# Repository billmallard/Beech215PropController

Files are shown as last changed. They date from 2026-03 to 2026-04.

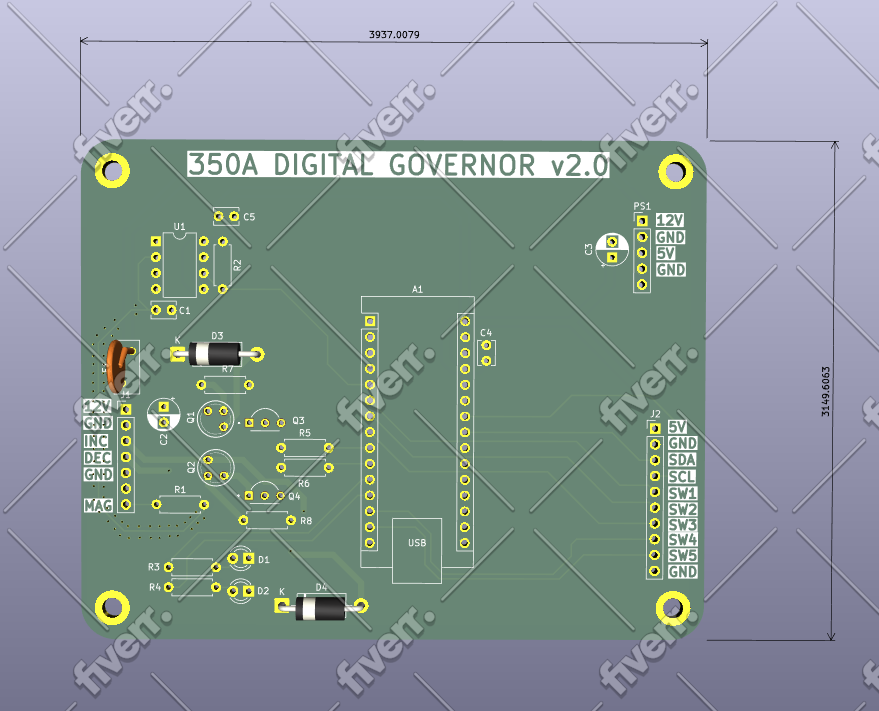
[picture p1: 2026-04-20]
hardware_april2026/Screenshot 2026-04-20 194752.png

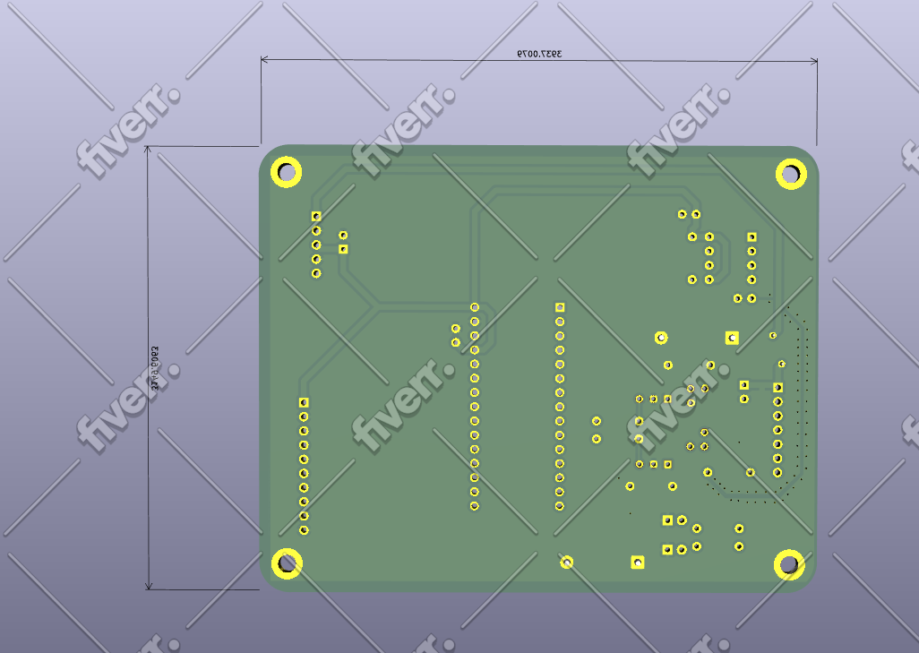
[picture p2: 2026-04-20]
hardware_april2026/Screenshot 2026-04-20 194800.png

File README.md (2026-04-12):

# Beechcraft Bonanza Electric Prop — Digital Governor Controller
### Open-Source Replacement for the Airborne Electronics 350A




> **A modern, proportional-control replacement for the Airborne Electronics 350A solid-state propeller governor — for Beechcraft Bonanza models with the Beech 215-210 electric prop.**

---

## The Problem This Solves

The original Airborne Electronics 350A (covered under STC SA2700WE) uses a **bang-bang control architecture** — the prop motor runs at full voltage until the RPM crosses the target, then reverses. This causes constant RPM hunting, which is made worse by:

- Freshly overhauled prop motors with more torque than the 50-year-old electronics expected
- Aging capacitors and resistors in the original controller that shrink the deadband
- The original panel rheostat giving no indication of what RPM is actually set
- Rough magneto signal from high-time mags degrading the RPM sensing

**This project replaces only the electronics inside the governor box.** The 7-pin Cannon connector, airframe wiring, prop motor, limit switches, and relays are all unchanged. From the aircraft's perspective, the interface is identical to the original.

## What It Does Differently

| Feature | Original 350A | This Controller |
|---|---|---|
| Control type | Bang-bang (full voltage on/off) | Proportional — slows motor near setpoint |
| Deadband | Fixed by aging analog components | Software-configurable (default ±25 RPM) |
| RPM display | None — knob position only | OLED shows set RPM and actual RPM |
| Presets | None | 5 named presets (Max, Cruise Climb, Cruise, Economy, Emergency) |
| Setpoint transition | Instant jump (causes full-duty relay surge) | Soft ramp 100 RPM/sec — smooth, no lurch |
| Fail-safe | RPM signal loss → no action | Loss of mag signal → relays de-energize, alarm displayed |
| Watchdog | None | Hardware watchdog resets MCU in 250ms if firmware stalls |
| Motor runaway protection | Limit switches only | 8-second relay timeout regardless of limit switch state |

## Who This Is For

Any Beechcraft Bonanza (straight 35 through G35, A35–G35) equipped with:
- The Beech 215-210 electric prop
- An existing Airborne Electronics 350A installation (STC SA2700WE)

If you have the stock mechanical governor, this is not applicable.

---

## Regulatory Note

This project is designed for **owner-produced parts** under 14 CFR Part 21.303. The STC SA2700WE defines the system by its external interface — the 7-pin connector, wire assignments, and functional behavior — all of which are preserved exactly. The electronics inside the governor housing are replaced. **This is a major alteration and requires FAA Form 337 approval signed by an IA.** See [docs/REGULATORY.md](docs/REGULATORY.md) for a detailed discussion and suggested 337 language.

---

## Hardware Overview

The system consists of two units:

**Governor Box** (replaces the 350A housing, mounts in the same location):
- Arduino Nano (ATmega328P)
- 6N137 optocoupler (galvanic isolation of magneto P-lead)
- ULN2003A Darlington array (relay driver)
- LM2596S-5V DC-DC switching regulator
- Supporting passives

**Panel Unit** (replaces the knob/rheostat assembly):
- SSD1306 1.3" OLED display (128×64, I2C)
- 5-position rotary switch (one detent per preset — Lorlin CK1024 or Grayhill 56-series)
- Original prop control knob reuses directly on the switch shaft

The PCB is a 100mm × 80mm 2-layer FR4 board, designed for JLCPCB fabrication at approximately **$2 for 5 boards**. The panel cable is 10 conductors (simplified from earlier designs).

---

## Repository Structure

```
bonanza-prop-governor/
├── README.md                    ← You are here
├── docs/
│   ├── ASSEMBLY.md              ← Step-by-step build instructions
│   ├── BENCH_TEST.md            ← Ground test procedure before aircraft installation
│   ├── WIRING.md                ← Connector pinout and wiring reference
│   ├── REGULATORY.md            ← FAA owner-produced parts guidance, 337 language
│   └── TROUBLESHOOTING.md       ← Fault codes, common issues
├── firmware/
│   └── governor_350A/
│       ├── README.md            ← Flashing guide, serial console, unit tests
│       ├── governor_350A.ino    ← Arduino sketch (fully commented)
│       ├── platformio.ini       ← PlatformIO build config (AVR + native test)
│       └── test/                ← Unity unit tests (runs on desktop, no hardware)
└── hardware/
    ├── 350A_governor.kicad_pcb  ← KiCad PCB file (open in KiCad 7+)
    ├── 350A_governor_JLCPCB.zip ← Ready-to-upload Gerber package for JLCPCB
    └── BOM.md                   ← Bill of materials with part numbers and sources
```

---

## Quick Start

1. **Order the PCB** — Upload `hardware/350A_governor_JLCPCB.zip` to [jlcpcb.com](https://jlcpcb.com). Default settings (2-layer, FR4, 1.6mm, HASL, green) are fine.
2. **Order components** — See [hardware/BOM.md](hardware/BOM.md). Total ~$55–95 for a complete build.
3. **Assemble** — Follow [docs/ASSEMBLY.md](docs/ASSEMBLY.md). All through-hole components; no SMD soldering.
4. **Flash firmware** — See [firmware/governor_350A/README.md](firmware/governor_350A/README.md) for full instructions (Arduino IDE, PlatformIO, and CLI). Set `PULSES_PER_REV` for your engine before flashing.
5. **Bench test** — Build the test harness described in [docs/BENCH_TEST.md](docs/BENCH_TEST.md) and verify operation before touching the aircraft.
6. **Install** — Follow [docs/ASSEMBLY.md](docs/ASSEMBLY.md) aircraft installation section. Have your IA present.

---

## Engine Compatibility

Set `PULSES_PER_REV` in the firmware before flashing:

| Engine | Cylinders | PULSES_PER_REV |
|---|---|---|
| Continental IO-470 | 6 | 3 |
| Continental IO-520 | 6 | 3 |
| Continental E-185/E-225 | 6 | 3 |
| Lycoming O-435 | 6 | 3 |

All early Bonanzas use Continental 6-cylinder engines. `PULSES_PER_REV = 3` is correct for all of them.

---

## Contributing

This project is maintained by the Bonanza owner community. Pull requests welcome for:
- Firmware improvements (better control algorithms, additional safety checks)
- Documentation corrections
- Hardware revisions (alternative component footprints, panel unit PCB)
- Flight test data and tuning recommendations

Please open an issue before starting significant work so efforts aren't duplicated.

---

## Security

This repository uses layered secret-prevention controls. See [SECURITY.md](SECURITY.md) for the full policy including vulnerability reporting and incident response steps.

| Layer | Tool | Trigger |
|---|---|---|
| Local pre-commit | `tools/security/scan_secrets.py` | Every `git commit` (staged files) |
| CI — SAST | CodeQL (C/C++ + Python) | Push, PR, weekly |
| CI — Secret scan | Gitleaks | Push, PR, weekly (full history) |

**Quick setup after cloning:**
```
pip install pre-commit
pre-commit install
```

Recommended GitHub repository settings: enable **Secret scanning**, **Push protection**, and **Dependabot** (Settings → Security).

---

## License

MIT License. See LICENSE file. This hardware and firmware may be freely built, modified, and used for personal aircraft. Commercial reproduction or sale requires separate arrangement.

---

## Acknowledgments

Richard Keiter of Airborne Electronics, Healdsburg CA, designed the original 350A and made it repairable by owners. This project is built on his philosophy. The complete original documentation is preserved in [docs/original_350A/](docs/original_350A/) for reference.

---

*This project is not affiliated with Beechcraft, Textron Aviation, or Airborne Electronics. It is an independent owner-community project. Install only with appropriate FAA authorization.*

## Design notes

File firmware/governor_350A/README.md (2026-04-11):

# Firmware — governor_350A

Arduino sketch for the Beechcraft Bonanza digital prop governor. Targets the **Arduino Nano (ATmega328P, 5V, 16MHz)**.

---

## Before You Flash

**One setting must be correct for your engine before uploading:**

```cpp
// governor_350A.ino — top of file
#define PULSES_PER_REV  3   // 6-cyl Continental (IO-470, IO-520, E-185/E-225)
                            // Change to 2 for 4-cylinder engines
```

All early Bonanzas use Continental 6-cylinder engines. `3` is correct for all of them. Getting this wrong causes the RPM reading to be off by 33% and the governor will not hold correctly.

---

## Flashing the Firmware

### Option A — Arduino IDE (simplest)

1. **Install Arduino IDE 2.x** from [arduino.cc/en/software](https://www.arduino.cc/en/software)

2. **Install required libraries** via *Tools → Manage Libraries*:
   - `Adafruit SSD1306` (by Adafruit) — installs `Adafruit GFX Library` automatically
   - Accept all dependency installs when prompted

3. **Open the sketch** — `File → Open → firmware/governor_350A/governor_350A.ino`

4. **Set the board** — *Tools → Board → Arduino AVR Boards → Arduino Nano*

5. **Set the processor** — *Tools → Processor → ATmega328P*
   > If upload fails with the default setting, try *ATmega328P (Old Bootloader)*. Nanos purchased after ~2018 typically have the old bootloader despite being sold as standard.

6. **Select the port** — *Tools → Port → COM? (Arduino Nano)*
   - On Windows: check Device Manager under Ports (COM & LPT)
   - On Mac/Linux: `/dev/cu.usbserial-*` or `/dev/ttyUSB*`

7. **Verify** (optional) — Click the tick icon (✓) to compile without uploading. Confirms no errors before touching the board.

8. **Upload** — Click the arrow icon (→). The IDE compiles and flashes. The Nano's RX/TX LEDs will blink rapidly during upload, then the board resets and runs.

9. **Open Serial Monitor** — *Tools → Serial Monitor*, baud rate `9600`. You should see:
   ```
   350A Digital Governor v2.0
   PULSES_PER_REV=3
   RAMP_RATE=100 RPM/sec
   Boot: SW position 3 (CRUISE)
   Ready. Type ? for commands.
   ```

---

### Option B — PlatformIO (recommended for ongoing development)

PlatformIO integrates with VS Code and handles library management automatically. A `platformio.ini` is included in this directory.

1. **Install VS Code** from [code.visualstudio.com](https://code.visualstudio.com)

2. **Install the PlatformIO IDE extension** — search *PlatformIO IDE* in the VS Code Extensions panel

3. **Open the firmware directory** — *File → Open Folder → firmware/governor_350A*
   > Open the `governor_350A` folder itself, not the repo root. PlatformIO expects `platformio.ini` to be at the folder root.

4. **Set `PULSES_PER_REV`** in `governor_350A.ino` if needed.

5. **Build** — Click the checkmark (✓) in the PlatformIO toolbar (bottom status bar), or run:
   ```
   pio run
   ```
   PlatformIO auto-downloads the AVR toolchain and Adafruit libraries on first build.

6. **Upload** — Connect the Nano via USB, then click the arrow icon (→) in the toolbar, or:
   ```
   pio run --target upload
   ```

7. **Serial monitor** — Click the plug icon in the toolbar, or:
   ```
   pio device monitor --baud 9600
   ```

**Expected build output (approximate):**
```
RAM:   [=======   ]  66.7% (used 1367 bytes from 2048 bytes)
Flash: [========  ]  78.1% (used 23998 bytes from 30720 bytes)
[SUCCESS]
```

Flash usage is high because the Adafruit SSD1306 + GFX libraries are large. There is approximately 6KB of flash headroom available. RAM has ~680 bytes free at runtime; the call stack lives here so don't add large local arrays.

---

### Option C — Arduino CLI (headless / automation)

Useful for CI or machines without a GUI.

1. **Install arduino-cli** — download from [arduino.cc/en/software](https://www.arduino.cc/en/software) (scroll to CLI section), or:
   ```bash
   # macOS
   brew install arduino-cli

   # Linux / Windows (PowerShell)
   curl -fsSL https://raw.githubusercontent.com/arduino/arduino-cli/master/install.sh | sh
   ```

2. **Initialize and install the AVR core:**
   ```bash
   arduino-cli config init
   arduino-cli core update-index
   arduino-cli core install arduino:avr
   ```

3. **Install required libraries:**
   ```bash
   arduino-cli lib install "Adafruit SSD1306"
   arduino-cli lib install "Adafruit GFX Library"
   ```

4. **Compile:**
   ```bash
   arduino-cli compile \
     --fqbn arduino:avr:nano:cpu=atmega328 \
     firmware/governor_350A/governor_350A.ino
   ```
   > For the old bootloader variant: `--fqbn arduino:avr:nano:cpu=atmega328old`

5. **Find the port:**
   ```bash
   arduino-cli board list
   ```

6. **Upload:**
   ```bash
   arduino-cli upload \
     --fqbn arduino:avr:nano:cpu=atmega328 \
     --port /dev/ttyUSB0 \
     firmware/governor_350A/governor_350A.ino
   ```
   Replace `/dev/ttyUSB0` with your actual port (`COMx` on Windows).

---

## Serial Debug Console

While the Nano is connected via USB, a debug console is available at **9600 baud**. Open any serial terminal (Arduino IDE Serial Monitor, PlatformIO monitor, `screen`, PuTTY, etc.).

| Command | Action |
|---|---|
| `?` | Print command help |
| `s` | Print full status line |
| `a` | Switch to AUTO mode |
| `m` | Switch to MANUAL mode, disable relays |
| `c` | Clear active alarm |
| `1`–`5` | Simulate rotary switch position (for bench testing without hardware) |

**Example status output (`s` command):**
```
Mode=AUTO SW=CRUISE Target=2300 Ramped=2300 ACT=2287 Err=13 Relay=OFF
```

When in AUTO mode, the status line prints automatically every 2 seconds.

---

## Unit Tests

The firmware includes a [Unity](https://github.com/ThrowTheSwitch/Unity)-based test suite that runs on the **native desktop** — no Arduino hardware required.

### What Is Tested

Tests mock all Arduino/AVR hardware APIs (GPIO, timers, EEPROM, I2C, watchdog) and compile the `.ino` directly as a C++ translation unit. This allows the pure logic functions to be executed and verified offline.

| Module | Test cases | What is verified |
|---|---|---|
| `calculateRPM()` | 6 | Zero when no pulse interval; zero when mag signal timeout; correct RPM at all four preset values (2200, 2300, 2450, 2650) with 3 PPR; rolling average dampens a spike without wild RPM reading |
| `magSignalLost()` | 3 | Returns false when signal is fresh; returns false 1 ms before the 2-second timeout; returns true 1 ms after the timeout |
| `updateRamp()` | 5 | Ramps up toward higher target at correct rate (100 RPM/sec); ramps down toward lower target; snaps to target when remaining gap is smaller than one step; never overshoots; skips entirely when fullCoarse preset is active |
| `runControlLoop()` | 10 | Commands INC relay when RPM is below setpoint; commands DEC relay when above; cuts off both relays inside the ±25 RPM deadband; does not act in MANUAL mode; triggers ALARM and de-energizes relays on mag signal loss; triggers ALARM on RPM below 400 or above 3500; drives DEC continuously in fullCoarse (EMERGENCY) mode; commands full relay duty when error ≥ PROP_ZONE_RPM; commands proportional duty when error is inside the proportional zone |

**Total: 24 tests, 0 failures.**

### What Is Not Testable Without Hardware

| Functionality | Why it can't be unit tested |
|---|---|
| `readSwitch()` debounce | Requires `digitalRead()` returning a changing sequence over real time. The static state variables inside the function also can't be reset from outside. |
| Relay contact waveform (actual duty cycle) | The proportional relay drive calculates `millis() % CONTROL_INTERVAL_MS` to place the on-pulse within the 100ms window. Verifying the GPIO waveform shape requires a real-time environment with accurate timer semantics. |
| OLED rendering | `updateDisplay()` has no observable output in a mock environment. OLED correctness is verified visually during bench test. |
| Watchdog reset behavior | The ATmega328P watchdog timer is a hardware peripheral. `wdt_enable()` / `wdt_reset()` are no-ops in the test mock. Watchdog function is inherent to the MCU and doesn't require software verification. |
| EEPROM persistence across power cycles | The mock EEPROM is a RAM array that resets at program start. Testing true non-volatile persistence requires either the physical chip or a more complete simulator. |
| `loadSettings()` round-trip | Depends on EEPROM persistence. Functional correctness is verified during bench test by power-cycling and confirming settings are retained. |
| Optocoupler signal conditioning | Analog/electrical behavior of the 6N137 (slew rate, noise rejection). Verified with an oscilloscope at the bench test stage per [docs/BENCH_TEST.md](../../docs/BENCH_TEST.md). |
| Full system integration | End-to-end behavior (mag signal → interrupt → RPM → relay → motor → RPM) requires the complete hardware assembly. See `docs/BENCH_TEST.md` for the full ground test procedure. |

### Running the Tests

#### With PlatformIO and GCC (Linux / macOS / Windows with MinGW)

```bash
cd firmware/governor_350A
pio test -e native
```

PlatformIO automatically downloads the Unity library and compiles the test suite. Requires `gcc` / `g++` in your PATH.

- **Linux:** `sudo apt install gcc build-essential`
- **macOS:** `xcode-select --install`
- **Windows:** Install [MSYS2](https://www.msys2.org), then `pacman -S mingw-w64-x86_64-gcc`, and add `C:\msys64\mingw64\bin` to your PATH

#### With MSVC on Windows (VS 2017/2019/2022 Build Tools)

A batch script is provided for Windows machines with Visual Studio Build Tools but no MinGW:

```bat
cd firmware\governor_350A
.pio\build_test.bat
.pio\test_firmware.exe
```

> `build_test.bat` is generated in `.pio\` (gitignored). If it's missing, re-run `pio test -e native` once — it will fail at link but will have downloaded Unity and created the `.pio` directories. Then recreate the batch file or compile manually using the MSVC command in the next section.

**Manual MSVC compile** (if the batch file is missing):
```bat
call "C:\Program Files (x86)\Microsoft Visual Studio\2017\BuildTools\VC\Auxiliary\Build\vcvars64.bat"

cl.exe /EHsc /std:c++14 /nologo ^
  /I "test\mocks" ^
  /I ".pio\libdeps\native\Unity\src" ^
  "test\test_firmware\test_firmware.cpp" ^
  ".pio\libdeps\native\Unity\src\unity.c" ^
  /Fe:".pio\test_firmware.exe"

.pio\test_firmware.exe
```

Adjust the VS path for your installed version (2017/2019/2022).

#### Expected output

```
test\test_firmware\test_firmware.cpp:319:test_rpm_zero_when_no_pulse_interval:PASS
test\test_firmware\test_firmware.cpp:320:test_rpm_zero_when_mag_signal_lost:PASS
...
test\test_firmware\test_firmware.cpp:348:test_control_proportional_duty_in_prop_zone:PASS

-----------------------
24 Tests 0 Failures 0 Ignored
OK
```

### Test File Layout

```
firmware/governor_350A/
├── governor_350A.ino          ← Firmware source
├── platformio.ini             ← Build config (AVR + native test environments)
└── test/
    ├── mocks/                 ← Arduino/AVR API stubs for native compilation
    │   ├── Arduino.h          ← millis(), micros(), digitalRead/Write, Serial, String
    │   ├── Wire.h             ← TwoWire stub
    │   ├── EEPROM.h           ← RAM-backed EEPROM stub
    │   ├── Adafruit_GFX.h     ← Empty stub (not exercised by logic tests)
    │   ├── Adafruit_SSD1306.h ← No-op method stubs
    │   └── avr/
    │       └── wdt.h          ← wdt_enable/wdt_reset no-ops
    └── test_firmware/
        └── test_firmware.cpp  ← 24 Unity test cases
```

---

## Tuning Parameters

All tuning constants are `#define`d at the top of the sketch. Defaults are conservative and appropriate for a first installation. Adjust after confirming basic operation.

| Constant | Default | Effect |
|---|---|---|
| `DEADBAND_RPM` | 25 | No correction within ±25 RPM of setpoint. Increase if relay chatters at target; decrease for tighter hold. |
| `PROP_ZONE_RPM` | 75 | Proportional slowdown starts this far from setpoint. Must be > `DEADBAND_RPM`. |
| `MIN_DUTY_PCT` | 25 | Minimum relay duty in the proportional zone (prevents relay from switching too briefly to move the motor). |
| `RAMP_RATE_RPM_PER_SEC` | 100 | How fast the setpoint walks to a new preset. At 100 RPM/sec, ECO→MAX (450 RPM) takes ~4.5 seconds. |
| `MAG_TIMEOUT_MS` | 2000 | Alarm if no magneto pulse for this long (engine idle produces ~90 Hz; 2 seconds is 180 missed pulses). |
| `MAX_RELAY_MS` | 8000 | Safety: cut relay if it's been continuously on for 8 seconds without the RPM moving. |
| `CONTROL_INTERVAL_MS` | 100 | Control loop cadence. Also the PWM period for proportional duty output. |

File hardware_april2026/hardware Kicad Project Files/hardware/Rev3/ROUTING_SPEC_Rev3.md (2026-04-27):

# 350A Governor PCB — Rev 3 Routing Specification
# High-Side Relay Driver (NPN + PNP)

This document gives **explicit pad-to-net assignments** for all new Rev 2 components.
Use it to assign nets in the PCB editor before routing traces.

---

## Footprint Pin Reference

### Q3, Q4 — 2N2222A NPN (footprint: `2N2222A:TO92254P470H750-3`)

Three inline pads. Square pad (pad 1) is marked with a silkscreen dot.
Looking at the **flat face** of the transistor body:

```
[Pad 1 / E]  [Pad 2 / B]  [Pad 3 / C]
  Emitter      Base        Collector
  (square)     (round)     (round)
```

### Q1, Q2 — 2N2907A PNP (footprint: `2N2907A_:TO18`)

> **Note:** The revision brief specified TO-92. The delivered footprint is TO-18 (metal can,
> triangular pin arrangement). Electrically compatible but physically different. If you wish
> to change to TO-92 for consistency with the brief, use the standard KiCad
> `Package_TO_SOT_THT:TO-92_Inline` footprint (EBC left-to-right). The pad assignments
> below are for the TO-18 footprint as placed.

Pin layout (view from bottom, leads facing you):

```
Pad 1 (E)   Pad 2 (B)
  (-1.27,    (+1.27,
   +1.27)     +1.27)

             Pad 3 (C)
             (+1.27,
              -1.27)
```

| Pad | Function |
|-----|---|
| 1 | Emitter  |
| 2 | Base |
| 3 | Collector|

---

## Required Net Assignment — Per Pad

### Channel 1 — INC (Q3, Q1, R5, R7, D4)

| Ref | Pad | Net | Notes |
|-----|-----|-----|---|
| Q3 | 1 (E) | `GND` | NPN emitter to ground |
| Q3 | 2 (B) | `Q3_BASE` | Receives drive signal via R5 |
| Q3 | 3 (C) | `Q3_COLL` | Shared node: R7 pin 1 + Q1 pad 2 |
| R5 | 1 | `Q3_BASE` | Connects to Q3 base |
| R5 | 2 | `D6_INC` | ✅ Already routed — do not change |
| R7 | 1 | `Q3_COLL` | Shared node with Q3 collector and Q1 base |
| R7 | 2 | `12V_RAW` | Pull-up to +12V — keeps PNP off when NPN is off |
| Q1 | 1 (E) | `12V_RAW` | PNP emitter to +12V supply rail |
| Q1 | 2 (B) | `Q3_COLL` | Shared node: Q3 collector + R7 pin 1 |
| Q1 | 3 (C) | `INC_RELAY` | Drives INC relay coil via J1 |
| D4 | 1 (cathode) | `12V_RAW` | ⚠️ Currently unrouted — must connect to +12V |
| D4 | 2 (anode) | `INC_RELAY` | ✅ Already routed — do not change |

**`Q3_BASE` and `Q3_COLL` are internal nets** — name them whatever you like in KiCad,
but they must connect *only* the pads listed above.

---

### Channel 2 — DEC (Q4, Q2, R6, R8, D3)

| Ref | Pad | Net | Notes |
|-----|-----|-----|---|
| Q4 | 1 (E) | `GND` | NPN emitter to ground |
| Q4 | 2 (B) | `Q4_BASE` | Receives drive signal via R6 |
| Q4 | 3 (C) | `Q4_COLL` | Shared node: R8 pin 1 + Q2 pad 2 |
| R6 | 1 | `Q4_BASE` | Connects to Q4 base |
| R6 | 2 | `D7_DEC` | ✅ Already routed — do not change |
| R8 | 1 | `Q4_COLL` | Shared node with Q4 collector and Q2 base |
| R8 | 2 | `12V_RAW` | Pull-up to +12V |
| Q2 | 1 (E) | `12V_RAW` | PNP emitter to +12V supply rail |
| Q2 | 2 (B) | `Q4_COLL` | Shared node: Q4 collector + R8 pin 1 |
| Q2 | 3 (C) | `DEC_RELAY` | Drives DEC relay coil via J1 |
| D3 | 1 (cathode) | `12V_RAW` | ✅ Already routed — do not change |
| D3 | 2 (anode) | `DEC_RELAY` | ✅ Already routed — do not change |

---

### Fuse — F1

> **Important:** F1 must be in *series* on the +12V input, not connected pad-to-pad on
> the same net. This requires splitting the existing `12V_RAW` net at the power input.

| Ref | Pad | Net | Notes |
|-----|-----|-----|---|
| F1 | 1 | `12V_IN` | From power input connector (upstream of fuse) |
| F1 | 2 | `12V_RAW` | Protected rail (downstream — feeds Q1/Q2 emitters, R7/R8) |

**How to implement in KiCad:**
1. Identify the pad on J1 (or PS1) that is the +12V input to the board.
2. Break the existing `12V_RAW` trace between that pad and the rest of the board.
3. Rename the power-input pad's net to `12V_IN`.
4. Route: connector `12V_IN` pad → F1 pad 1 → F1 pad 2 → existing `12V_RAW` bus.

---

## Errors to Correct in Current Revision

The following incorrect connections from the current PCB must be **removed** before re-routing:

| Ref | Pad | Current (wrong) net | Correct net |
|-----|-----|---|---|
| Q3  | 2 | `GND` | `Q3_BASE` |
| Q4  | 2 | `GND` | `Q4_BASE` |
| Q1  | 1 | `DEC_RELAY` | `12V_RAW` |
| Q2  | 1 | `INC_RELAY` | `12V_RAW` |
| F1  | 1 | `12V_RAW` | `12V_IN` |
| F1  | 2 | `12V_RAW` | `12V_RAW` (unchanged but pad 1 must change) |

---

## What Was Correct (do not change)

| Ref | Pad | Net | Status |
|-----|-----|-----|---|
| R5 | 2 | `D6_INC` | ✅ |
| R6 | 2 | `D7_DEC` | ✅ |
| D3 | 1 | `12V_RAW` | ✅ |
| D3 | 2 | `DEC_RELAY` | ✅ |
| D4 | 2 | `INC_RELAY` | ✅ |

---

## Re-run DRC After Routing

The existing DRC report (`DRC.rpt`) is dated **2026-03-12** and does not reflect the
Rev 2 components. After completing all net assignments and routing:

1. **Edit → Fill All Zones** (refresh GND pour)
2. **Inspect → Design Rules Checker** — must show 0 errors, 0 unconnected pads
3. Save a new `DRC.rpt`
4. Regenerate Gerbers: **File → Fabrication Outputs → Gerbers**

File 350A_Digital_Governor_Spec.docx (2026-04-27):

Airborne Electronics 350A

Digital Propeller Governor Replacement

Technical Specification · Revision 3.0 · April 2026

An open-source digital replacement for the Airborne Electronics 350A propeller governor, designed for Beechcraft Bonanza aircraft equipped with the Hartzell electric propeller system under STC SA2700WE.

GitHub: https://github.com/billmallard/Beech215PropController

Reference Aircraft: Beechcraft A-35 Bonanza

FOR EXPERIMENTAL AND DEVELOPMENT USE ONLY — NOT FAA APPROVED

# 1. Project Overview

This project implements a digital drop-in replacement for the Airborne Electronics 350A propeller governor used on Beechcraft Bonanza aircraft equipped with the Hartzell electric propeller pitch control system. The original 350A uses analog bang-bang (on/off) control logic with a panel rheostat for RPM selection. This replacement retains full electrical compatibility with the aircraft's existing 7-pin MS3106 cannon connector wiring while replacing the control logic with a microcontroller-based PID-influenced governor featuring a 5-position rotary switch for discrete RPM preset selection.

## 1.1 Design Goals

- Drop-in electrical replacement — no aircraft wiring modifications required
- Eliminate RPM hunting present in worn or aging 350A units
- Precise RPM hold using digital pulse counting from the magneto P-lead
- Five discrete RPM presets via panel-mounted rotary switch
- OLED display showing live RPM, selected mode, and governor status
- Open-source hardware and firmware for community improvement
- Custom-machined aluminum panel inserts for a factory-quality cockpit appearance

## 1.2 Compatibility

Parameter | Value
Aircraft | Beechcraft 35-series Bonanza (A-35 and variants)
Engine | Continental IO-470 / IO-520 (6-cylinder)
Propeller System | Hartzell electric pitch change motor
STC | SA2700WE (Airborne Electronics 350A)
Connector | Amphenol MS3106A-14S-7S (7-pin circular)
Aircraft Power | 12V DC nominal (11–14V operating range)

# 2. System Architecture

The controller is built around an Arduino Nano (ATmega328P) with supporting circuitry on a custom 2-layer PCB. The design uses optocoupler isolation on the magneto pulse input, NPN+PNP discrete transistor pairs (Q1–Q4) for relay drive, and a regulated 5V supply derived from aircraft 12V bus power.

## 2.1 Signal Chain

- Magneto P-lead (Pin H) → 10kΩ isolating resistor → 6N137 optocoupler → Arduino INT0 (D2)
- Arduino D6/D7 → NPN+PNP transistor pairs (Q3/Q1, Q4/Q2) → INC/DEC relay coils (Pin C / Pin D)
- Panel rotary switch (5-position) → Arduino D3/D4/D5/D10/D11
- Arduino A4/A5 (I2C SDA/SCL) → 0.96" OLED display (SSD1306)
- Aircraft 12V (Pin A) → LM2596 buck module → 5V regulated → Arduino Nano VIN

## 2.2 RPM Sensing

RPM is derived from the right magneto P-lead pulse train. The Continental IO-470/IO-520 fires 3 pulses per revolution (one per cylinder pair per rotation). The 6N137 high-speed optocoupler provides electrical isolation from the magneto circuit and level-shifts the signal to 5V logic. The Arduino captures rising edges on INT0 using hardware interrupt, computing RPM over a 250ms measurement window for a balance of responsiveness and stability.

NOTE: The 10kΩ series resistor on Pin H is part of the original 350A wiring harness. This resistor must remain in the circuit. Do not bypass it.

## 2.3 Governor Logic

The governor uses a three-zone control strategy:

- Deadband (±25 RPM): No relay action. Prevents relay chatter at steady cruise.
- Proportional Zone (±75 RPM): Relay pulse duration scaled to error magnitude. Provides smooth, damped correction.
- Full Correction (>75 RPM error): Maximum relay duration (capped at 8 seconds) for large deviations.

On RPM preset change, the target ramps at 100 RPM/second to prevent abrupt pitch commands. Position 5 (EMER) bypasses governor logic entirely and commands immediate full-coarse pitch.

# 3. Hardware

## 3.1 PCB Specifications

Parameter | Specification
Board Size | 100mm × 80mm
Layers | 2-layer FR4
Copper Weight | 1oz
Surface Finish | HASL or ENIG
Mounting | 4× M3 through-holes at corners
PCB Tool | KiCad 10
Fab Target | JLCPCB (2-layer, standard spec)

## 3.2 Component List

Ref | Component | Value/Type | Part / Source | Notes
A1 | Arduino Nano | ATmega328P | LAFVIN Nano V3.0 / Amazon | CH340 USB; install driver
U1 | Optocoupler | 6N137 | DigiKey #1731495 | DIP-8; Vishay
PS1 | Buck Regulator | LM2596 5V | Amazon 5-pack | Adjust to 5.0V before install
J1 | Governor Connector | 7-pin MS3106A | Aircraft Spruce / DigiKey | MS3106A-14S-7S mating plug
J2 | Panel Connector | 10-pin header | 2.54mm male header | Switch + display harness
DISP | OLED Display | 1.3" SSD1306 | UCTRONICS / Amazon | I2C 0x3C; yellow+blue
R1 | Resistor | 10kΩ | DigiKey 10KEBK-ND | Magneto input isolation
R2 | Resistor | 4.7kΩ | DigiKey 4.7KEBK-ND | Optocoupler bias
R3, R4 | Resistors | 330Ω (×2) | DigiKey 330EBK-ND | LED current limit
C1, C4, C5 | Capacitors | 100nF (×3) | BOJACK 104 / Amazon | Ceramic disc bypass
C2 | Capacitor | 100µF 25V | Tnisesm / Amazon | Electrolytic; polarity critical
C3 | Capacitor | 47µF 10V | Tnisesm / Amazon | Electrolytic; polarity critical
D1, D2 | LEDs | 3mm red/green | DigiKey (exact match) | INC/DEC status indicators
Q1, Q2 | Transistor | 2N2907A PNP TO-92L | DigiKey 2N2907A-ND | High-side relay driver; 2x per channel
Q3, Q4 | Transistor | 2N2222A NPN TO-92 | DigiKey 2N2222A-ND | NPN level shifter; driven by Nano D6/D7
R5, R6 | Resistors | 1kΩ (x2) | DigiKey 1.0KEBK-ND | NPN base resistors (Q3, Q4)
R7, R8 | Resistors | 10kΩ (x2) | DigiKey 10KEBK-ND | PNP base pull-ups (Q1, Q2)
D3, D4 | Diodes | 1N4001 (x2) | DigiKey 1N4001FSCT-ND | Flyback; cathode to +12V; do not omit
F1 | PTC Fuse | 1A resettable | Bel Fuse 0ZRE or equiv. | In series with 12V_RAW; self-resets on overcurrent

## 3.3 7-Pin Connector Pinout

The MS3106A-14S-7S connector mates directly to the existing aircraft wiring harness. Pin designations are identical to the original 350A:

Pin | Signal | Description
A | 12V_RAW | Aircraft bus power (switched via prop toggle)
B | GND | Aircraft ground
C | INC_RPM | Increase RPM relay output (fine pitch command)
D | DEC_RPM | Decrease RPM relay output (coarse pitch command)
E | GND (new) | Panel pot low side — tied to GND in this design
F | GND (new) | Panel pot high side — tied to GND in this design
H | MAG_PULSE | Right magneto P-lead via 10kΩ series resistor

NOTE: Pins E and F previously connected to the panel rheostat wiper. In this design both are tied to ground. The rotary switch replaces rheostat-based RPM selection entirely.

# 4. Firmware

## 4.1 Overview

Firmware is written in C++ for the Arduino framework (avr-gcc). The main control loop runs at approximately 250ms intervals, computing RPM from interrupt-counted pulses and issuing relay commands based on the three-zone control strategy described in Section 2.3.

## 4.2 Key Constants

Constant | Value | Description
PULSES_PER_REV | 3 | Continental 6-cyl (IO-470/IO-520)
DEADBAND | 25 RPM | No-action zone around target
PROP_ZONE | 75 RPM | Proportional control band
MAX_RELAY_MS | 8000 ms | Maximum single relay pulse duration
RAMP_RATE_RPM_PER_SEC | 100 RPM/s | Target RPM ramp rate on preset change
SWITCH_SETTLE_MS | 80 ms | Rotary switch debounce delay
MEAS_WINDOW_MS | 250 ms | RPM measurement integration window

## 4.3 Arduino Nano Pin Assignment

Pin | Signal | Function
D2 (INT0) | RPM_PULSE | Magneto pulse input — hardware interrupt
D3 | SW_POS1 | Rotary switch position 1 (MAX 2650)
D4 | SW_POS2 | Rotary switch position 2 (CLIMB 2450)
D5 | SW_POS3 | Rotary switch position 3 (CRUISE 2300)
D6 | INC_RELAY | Increase RPM relay drive (via Q3/Q1 transistor pair)
D7 | DEC_RELAY | Decrease RPM relay drive (via Q4/Q2 transistor pair)
D8 | INC_LED | Increase RPM indicator LED (D1)
D9 | DEC_LED | Decrease RPM indicator LED (D2)
D10 | SW_POS4 | Rotary switch position 4 (ECON 2200)
D11 | SW_POS5 | Rotary switch position 5 (EMER / Full Coarse)
A4 (SDA) | OLED_SDA | I2C data — OLED display
A5 (SCL) | OLED_SCL | I2C clock — OLED display

## 4.4 RPM Presets — 5-Position Rotary Switch

Position | Label | Target RPM | Behavior
1 | MAX / 2650 | 2650 | Full takeoff/go-around RPM; governs actively
2 | CLIMB / 2450 | 2450 | Climb power; governs actively
3 | CRUISE / 2300 | 2300 | Standard cruise; governs actively
4 | ECON / 2200 | 2200 | Economy cruise; governs actively
5 | EMER / COARSE | N/A | Bypasses governor; commands immediate full coarse pitch

WARNING: Position 5 (EMER) commands immediate full-coarse pitch without ramping. This is intentional emergency behavior. Appropriate panel labeling and physical detent or guard on the switch is strongly recommended.

# 5. OLED Display

A 0.96" SSD1306 OLED (128×64 pixels, I2C at address 0x3C) provides pilot-readable governor status. The display uses a yellow/blue bicolor module: the top 16 pixels illuminate yellow, the bottom 48 pixels illuminate blue. This maps naturally to a status header and data area.

## 5.1 Display Layout

Zone | Color | Content
Top strip (px 0–15) | Yellow | "PROP RPM CTRL" — fixed header
Main area (px 16–47) | Blue | Live RPM readout — large font (32pt)
Status bar (px 48–63) | Blue | MODE: [label] | GOVERNING / FULL COARSE

# 6. Panel Installation

## 6.1 Concept

The rotary switch and OLED display are mounted in standard 3.125" instrument blank openings — the same size used by most Bonanza panel instruments. This allows the controller to be installed in any unused blank slot without panel modification. Custom aluminum faceplates machined by Front Panel Express (frontpanelexpress.com) provide a professional, engraved finish.

## 6.2 Panel Faceplate Specification

Parameter | Specification
Blank Size | 3.125" (79.4mm) diameter
Material | 0.063" aluminum
Finish | Black anodize
Engraving Fill | White (standard positions) / Red (EMER label)
Rotary Shaft Hole | Per switch spec (typically 6mm or 0.25")
OLED Cutout | Approx. 25mm × 13mm display window
Label Layout | Two-line engraving: mode name over RPM value
Supplier | Front Panel Express (frontpanelexpress.com)
Panel C-C Spacing | 4.5" center-to-center (adjacent standard blanks)

## 6.3 Switch Position Labels

Position | Line 1 | Line 2 | Switch Angle | Color
1 | MAX | 2650 | -150° | White fill
2 | CLIMB | 2450 | -75° | White fill
3 | CRUISE | 2300 | 0° (12 o'clock) | White fill
4 | ECON | 2200 | +75° | White fill
5 | EMER | COARSE | +150° | Red fill — distinct warning color

NOTE: Position angles assume a 300° total travel arc (standard for most quality rotary switches). Confirm detent positions match the purchased switch before drilling the panel faceplate.

# 7. Regulatory Status

WARNING: This device is not FAA approved and does not have an STC. It replaces a component covered under STC SA2700WE, which belongs to Airborne Electronics. Installation in an FAA-certificated aircraft requires appropriate regulatory authorization.

The following pathways exist for legal installation:

- Experimental Amateur-Built Aircraft: No regulatory barrier. Owner-builders may install freely.
- Experimental Exhibition / Racing: Owner may install under operating limitations.
- Standard Category Aircraft (e.g., certificated Bonanza): Requires FAA Form 337 field approval under 14 CFR Part 43, or a new STC. Consult a DER (Designated Engineering Representative) or FSDO.
- Owner-performed maintenance: Even with appropriate authorization, the installation may only be performed by (or under the supervision of) a licensed A&P mechanic or the aircraft owner under 14 CFR 43.3(d) for certain items.

NOTE: This project is developed and tested on a Beechcraft A-35 Bonanza operated under standard category certification. All bench and flight testing is conducted by a licensed pilot and documented for potential future regulatory submission.

# 8. Development Status

Milestone | Status | Notes
Firmware v2.0 (5-position switch, ramping) | Complete
KiCad PCB schematic + placement | Complete | Routed by contractor
PCB routing | Complete | Completed by Fiverr contractor; V3.1 approved 2026-04-27
BOM sourcing | Complete | LEDs, passive, ICs, Nano ordered
Cannon connector (MS3106A-14S-7S) | Pending order | Aircraft Spruce / DigiKey
5-position rotary switch | Pending selection | SP5T, 300° travel, panel mount
Project box / enclosure | Pending | Hammond aluminum series
Panel faceplates (Front Panel Express) | Pending design file | After switch selection
PCB fabrication (JLCPCB) | Ordered | Ordered 2026-04-27 via JLCPCB
Board assembly | Pending fab | Building 2 units simultaneously
Bench test | Pending assembly | Full test procedure documented
Aircraft installation and flight test | Pending bench test

# 9. Contributing & Contact

This project is open-source and welcomes collaboration from pilots, avionics engineers, and embedded developers. The GitHub repository contains all firmware source, KiCad project files, BOM, assembly instructions, bench test procedure, and wiring documentation.

- GitHub: https://github.com/billmallard/Beech215PropController
- Issues and pull requests welcome
- Particularly seeking: DER contacts, additional aircraft type testing (E-series, F-series Bonanza, other Hartzell electric prop installations)

# 10. Disclaimer

This project is provided for educational and experimental purposes. The authors make no warranty regarding airworthiness, reliability, or suitability for use in aircraft. Propeller control system failures can be hazardous. Any use of this design in an aircraft is solely at the operator's risk and must comply with all applicable FAA regulations. This project is not affiliated with Airborne Electronics or Hartzell Propeller.

— End of Document —

FOR EXPERIMENTAL AND DEVELOPMENT USE ONLY · Page

350A Digital Propeller Governor · Technical Specification · Rev 1.0 · March 2026

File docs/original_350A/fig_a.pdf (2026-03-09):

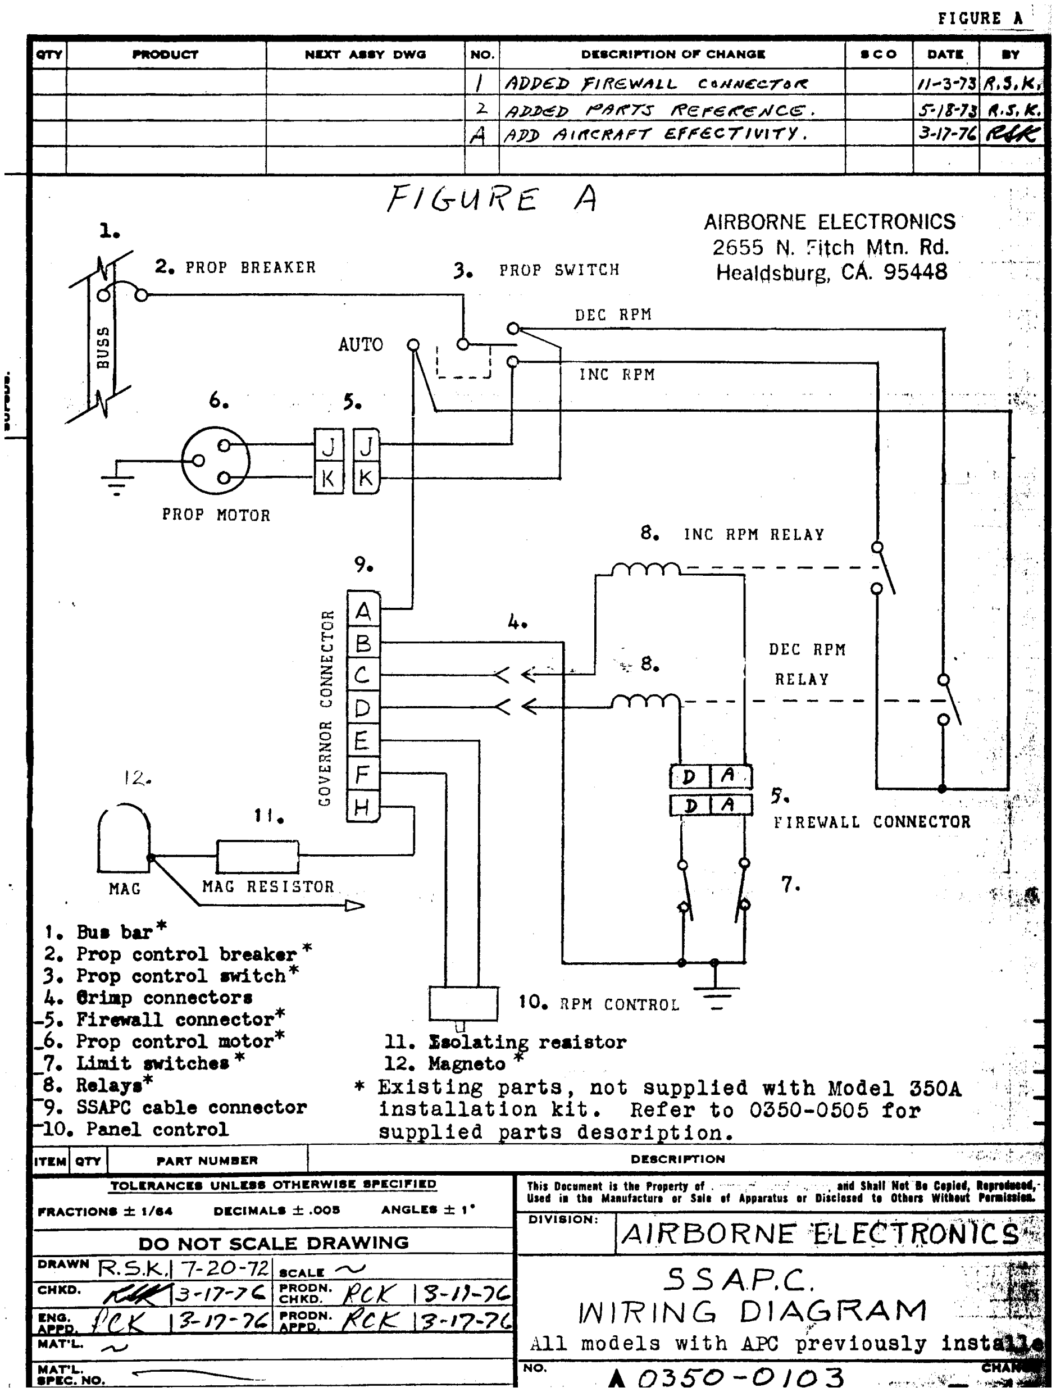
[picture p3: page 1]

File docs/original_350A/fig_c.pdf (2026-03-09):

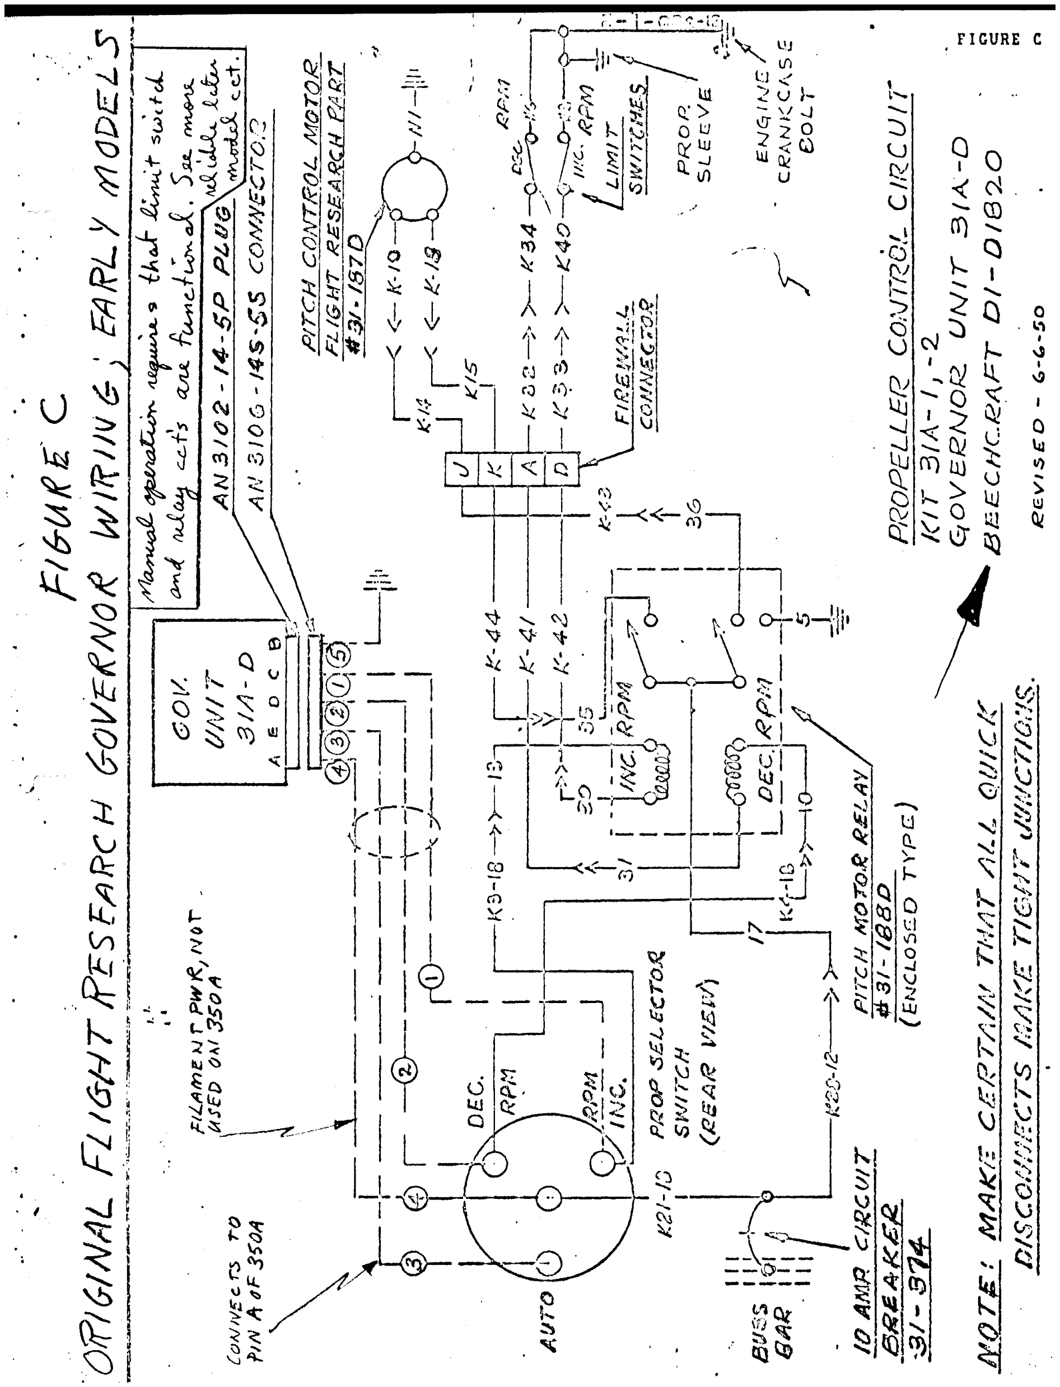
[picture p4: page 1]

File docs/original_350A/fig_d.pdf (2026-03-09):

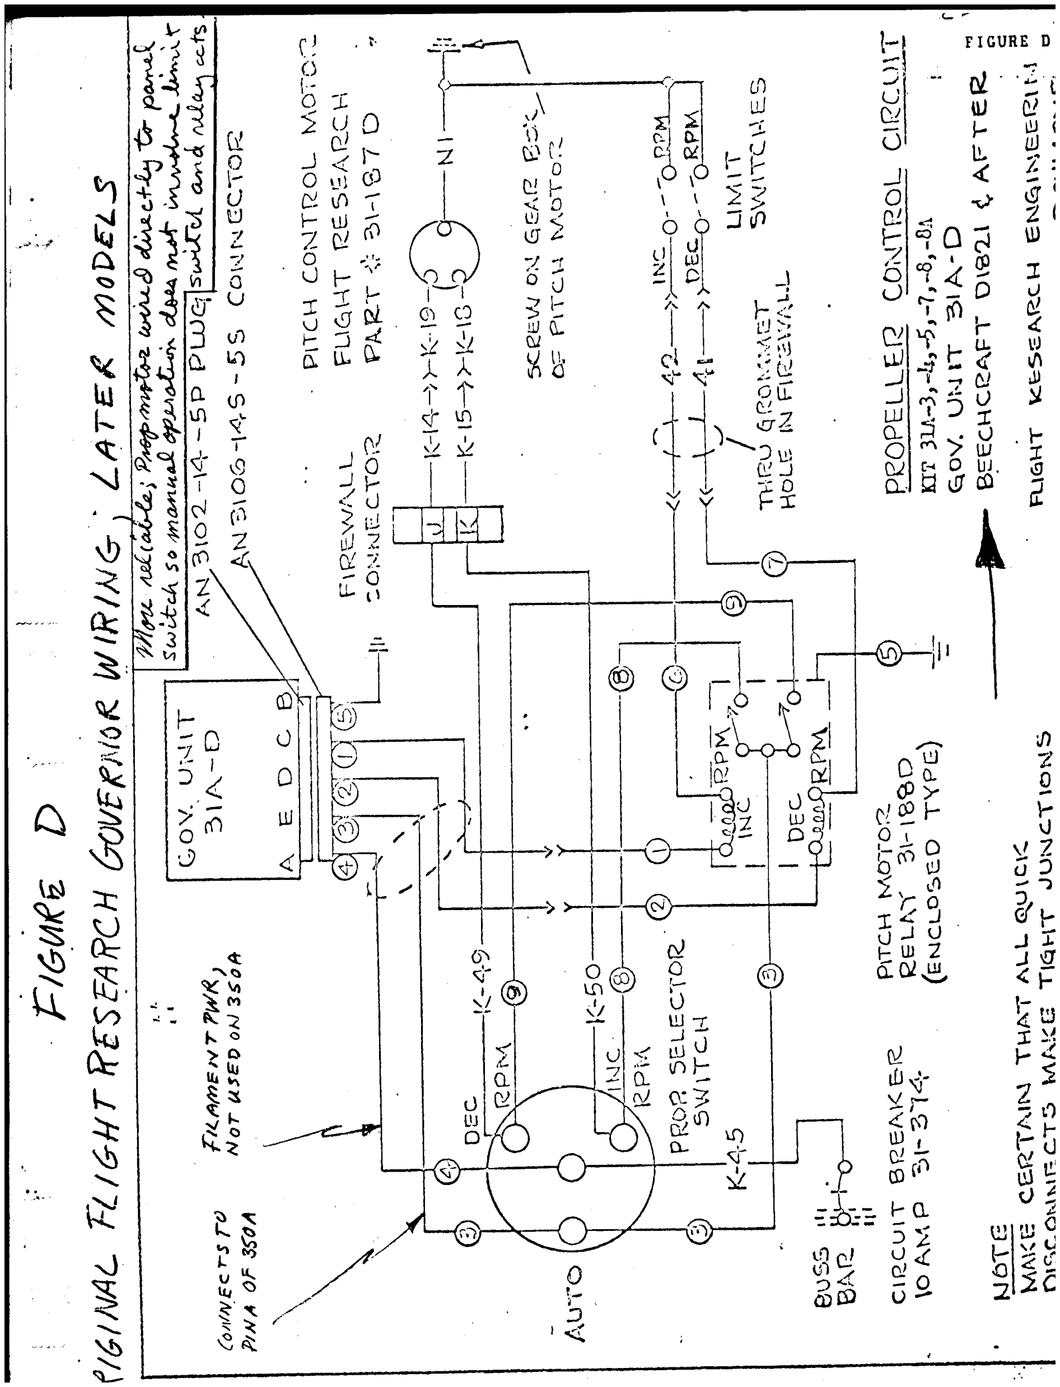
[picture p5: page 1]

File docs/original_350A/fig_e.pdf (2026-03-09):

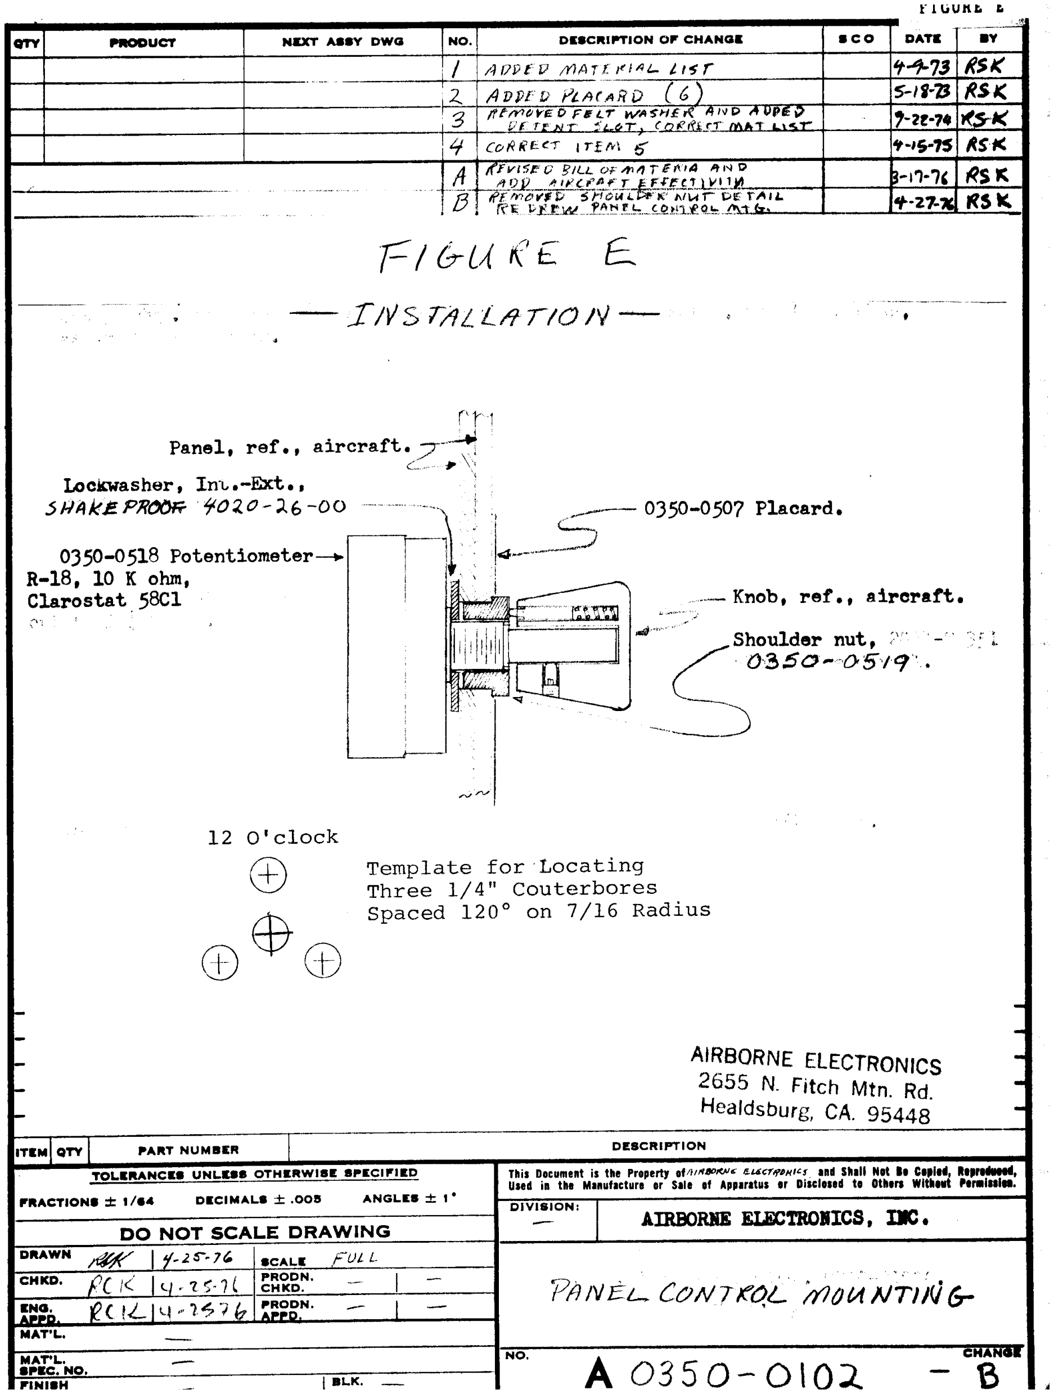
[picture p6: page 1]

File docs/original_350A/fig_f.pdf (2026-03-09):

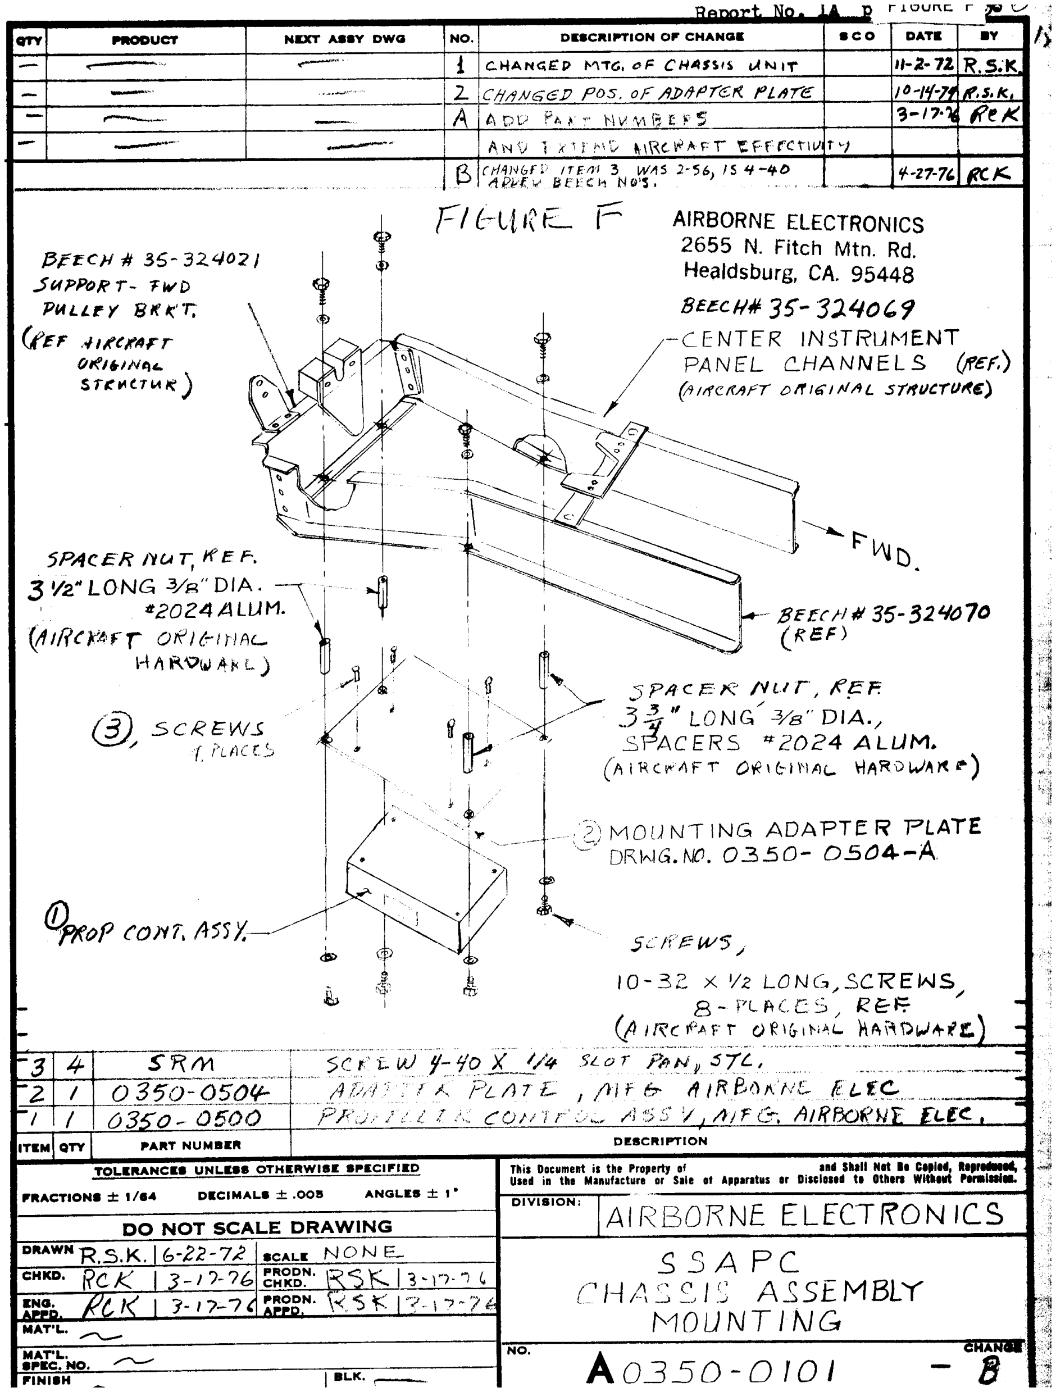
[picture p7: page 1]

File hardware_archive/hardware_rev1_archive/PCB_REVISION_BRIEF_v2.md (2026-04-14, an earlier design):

# PCB Revision Brief — Governor 350A, Rev 2

**Summary:** Replace U2 (ULN2003A, DIP-16) with a two-channel NPN+PNP high-side relay driver. All other components, board outline, and connector positions are unchanged.

**Background:** The Bonanza relay coil circuit is high-side driven — the governor supplies +12V to the relay coil and the other end grounds through the pitch-limit switch. The ULN2003A is an NPN low-side switch (sinks to GND) and is incompatible with this topology. The replacement circuit uses a standard NPN level-shifter + PNP high-side switch pair per channel, which is driven directly from 5V logic and switches +12V to the relay coil. No firmware changes are required.

---

## Remove

- U2 (ULN2003A, DIP-16) and its socket footprint
- All traces connected to U2 pins

---

## Add — Two-Channel High-Side Driver

Two identical channels (INC and DEC), each consisting of one NPN transistor, one PNP transistor, and two resistors.

*Channel 1 — INC (ref des: Q3, Q1, R5, R7)*
*Channel 2 — DEC (ref des: Q4, Q2, R6, R8)*

| Ref | Part | Footprint | Value |
|---|---|---|---|
| Q1, Q2 | 2N2907A | TO-92, inline (EBC pin order) | PNP — high-side switch |
| Q3, Q4 | 2N2222A | TO-92, inline (EBC pin order) | NPN — level shifter |
| R5, R6 | Resistor | Through-hole, 1/4W, 0.1" pitch | 1kΩ |
| R7, R8 | Resistor | Through-hole, 1/4W, 0.1" pitch | 10kΩ |

### Connections per channel (shown for INC; DEC is identical)

```
Nano D6 ──── R5 (1kΩ) ──── Q3 Base
                            Q3 Emitter ──── GND
                            Q3 Collector ──+──── R7 (10kΩ) ──── +12V_RAW
                                           |
                                       Q1 Base
                                       Q1 Emitter ──── +12V_RAW
                                       Q1 Collector ──── J1-C (INC_RELAY net)
```

For the DEC channel: Nano D7 → R6 → Q4; Q4 collector → R8/Q2 base; Q2 collector → J1-D (DEC_RELAY net). All other connections identical.

### How it works

- **Relay ON:** Nano drives pin HIGH (5V) → Q3/Q4 NPN turns on → collector pulled to ~GND → Q1/Q2 PNP base near GND → V_BE ≈ −12V → PNP fully on → +12V appears on J1-C or J1-D → relay energized
- **Relay OFF:** Nano drives pin LOW → NPN off → R7/R8 pulls PNP base to +12V → V_BE ≈ 0V → PNP off → relay de-energized

---

## Add — Flyback Protection Diodes

Clamp the inductive voltage spike from the relay coil when the PNP transistor switches off. Do not omit.

| Ref | Part | Footprint | Placement |
|---|---|---|---|
| D3 | 1N4001 | DO-41, through-hole | Anode → J1-C (INC_RELAY net); Cathode → +12V_RAW |
| D4 | 1N4001 | DO-41, through-hole | Anode → J1-D (DEC_RELAY net); Cathode → +12V_RAW |

---

## Add — Input Fuse Protection

The production A350 governor includes a fuse on the +12V input. This board should do the same. Add a nano (mini blade) fuse holder in series with the +12V_RAW input line, between the board's power input connector and the rest of the circuit.

| Ref | Part | Footprint | Value |
|---|---|---|---|
| F1 | Nano blade fuse holder | Through-hole, PCB-mount | 1A (fuse rating TBD — see note) |

**Note:** Select fuse rating based on relay coil current plus any other +12V loads on the board. A 1A nano fuse is a suggested starting point; confirm against the relay datasheet and total steady-state current draw before finalizing.

---

## Constraints

- Board outline, mounting holes, and all connector positions (J1, J2, J3, PS1) must remain **identical to Rev 1** — the board fits inside an existing enclosure
- All other components (U1, A1, PS1, OLED, passives) are unchanged
- Through-hole components throughout — no SMD

---

## Deliverables

- Updated KiCad schematic (`.kicad_sch`)
- Updated KiCad PCB layout (`.kicad_pcb`)
- Updated Gerber zip ready for JLCPCB (2-layer, standard settings)

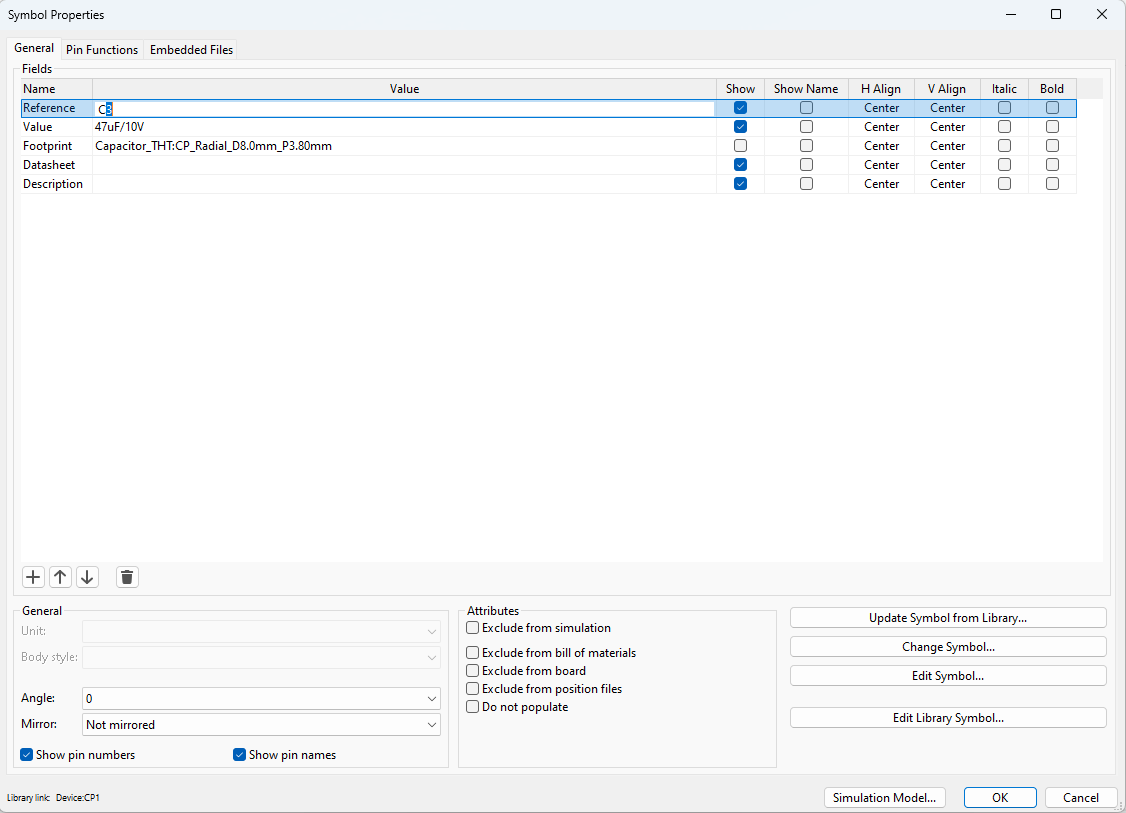
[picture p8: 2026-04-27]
hardware_rev3_1/image.png

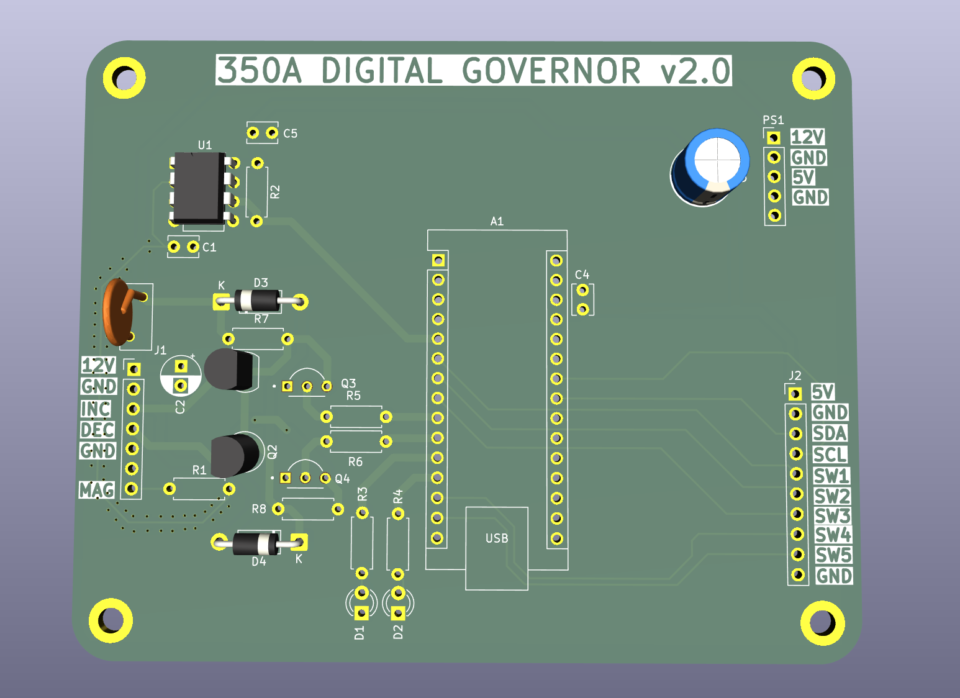
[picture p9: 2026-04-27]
hardware_rev3_1/Screenshot 2026-04-27 080713.png

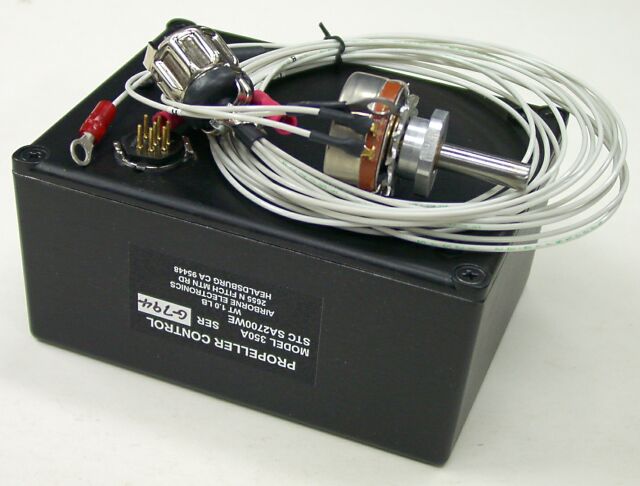
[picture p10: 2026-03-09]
docs/original_350A/gov.jpg

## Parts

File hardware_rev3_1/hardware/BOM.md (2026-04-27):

# Bill of Materials — Rev 3

Complete parts list for one governor build. All parts available from Digi-Key, Mouser, or Amazon.
Links are to Digi-Key where possible — they're reliable, stock everything, and ship fast.

**Estimated total cost: $60–100** depending on sourcing (Amazon vs. Digi-Key, bulk vs. singles)

---

## PCB

| Item | Specification | Qty | Source | Est. Cost | Notes |
|---|---|---|---|---|---|
| Governor PCB | 100×80mm 2-layer FR4 | 5 | JLCPCB | ~$2 + shipping | Upload Gerber zip from `production/` folder; default settings; you get 5, use 1 |

**JLCPCB order settings:**
- Base Material: FR4
- Layers: 2
- PCB Thickness: 1.6mm
- Surface Finish: HASL (with lead) — cheapest and fine for this application
- Copper Weight: 1oz
- Everything else: defaults

---

## ICs and Active Components

| Ref | Part | Description | Digi-Key PN | Qty | Est. Cost | Notes |
|---|---|---|---|---|---|---|
| A1 | Arduino Nano (ATmega328P) | Microcontroller | — | 1 | $4–8 | Buy the CH340 version (most common on Amazon/eBay). Avoid Nano Every — different pinout. |
| U1 | 6N137 | High-speed optocoupler | 516-2878-5-ND | 1 | $0.60 | DIP-8. Do not substitute 4N25/4N35 — too slow for mag pulses. |
| PS1 | LM2596S-5V Module | DC-DC 5V switching regulator | — | 1 | $1–3 | Pre-built module. **Must be labeled "5V" not adjustable.** Verify output before installing. Available on Amazon, 10-packs for $8. |
| OLED | SSD1306 1.3" OLED | I2C display 128×64 | — | 1 | $6–10 | Must be I2C (2-wire), 128×64. Many on Amazon. Verify module is 4-pin (VCC/GND/SCL/SDA). |

---

## Transistors — High-Side Relay Driver

Two-channel NPN+PNP circuit replacing the ULN2003A from Rev 2. All TO-92 package.

| Ref | Part | Type | Digi-Key PN | Qty | Est. Cost | Notes |
|---|---|---|---|---|---|---|
| Q1, Q2 | 2N2907A | PNP — high-side switch | 2N2907A-ND | 2 | ~$0.50 ea | TO-92L. Switches +12V to relay coil. |
| Q3, Q4 | 2N2222A | NPN — level shifter | 2N2222A-ND | 2 | ~$0.30 ea | TO-92. Driven by Nano 5V logic. |

---

## Passives — Resistors

All resistors: 1/4W metal film, 1% tolerance

| Ref | Value | Digi-Key PN | Qty | Notes |
|---|---|---|---|---|
| R1 | 10kΩ | 10KEBK-ND | 1 | Magneto input current limit |
| R2 | 4.7kΩ | 4.7KEBK-ND | 1 | Optocoupler pull-up |
| R3, R4 | 330Ω | 330EBK-ND | 2 | LED current limiters |
| R5, R6 | 1kΩ | 1.0KEBK-ND | 2 | NPN base resistors (Q3, Q4) |
| R7, R8 | 10kΩ | 10KEBK-ND | 2 | PNP base pull-up to +12V (Q1, Q2) |

**Tip:** R1, R7, R8 are all 10kΩ — order 4 total on a single line item.

---

## Passives — Capacitors

| Ref | Value | Type | Digi-Key PN | Qty | Notes |
|---|---|---|---|---|---|
| C1, C4, C5 | 100nF (0.1µF) | Ceramic disc | 445-173-ND | 3 | Non-polarized; marked "104" |
| C2 | 100µF 25V | Electrolytic | 493-1215-ND | 1 | **POLARIZED** — observe polarity. 12V input bulk cap. |
| C3 | 47µF 10V | Electrolytic | 493-1205-ND | 1 | **POLARIZED** — observe polarity. 5V output filter cap. |

---

## Protection — Diodes and Fuse

| Ref | Part | Digi-Key PN | Qty | Notes |
|---|---|---|---|---|
| D3, D4 | 1N4001 | 1N4001FSCT-ND | 2 | Flyback diodes — clamp relay coil inductive spike when PNP switches off. **Do not omit.** Observe polarity (cathode to +12V). |
| F1 | 1A PTC resettable fuse | — | 1 | In series with +12V_RAW input. Self-resets after overcurrent. Belkin/Bel Fuse 0ZRE or equivalent. |

---

## Indicators

| Ref | Part | Digi-Key PN | Qty | Notes |
|---|---|---|---|---|
| D1 | 3mm Red LED | 754-1264-ND | 1 | Standard brightness; INC indicator |
| D2 | 3mm Green LED | 754-1221-ND | 1 | Standard brightness; DEC indicator |

---

## Connectors and Sockets

| Ref | Part | Qty | Notes |
|---|---|---|---|
| — | DIP-8 socket | 1 | For U1 (6N137). Use machined-pin (turned-pin) type for reliability. |
| — | 15-pin female single-row socket strip | 2 | For Arduino Nano. Cut to length or buy pre-cut Nano socket kit. |
| J1 | 1×7 2.54mm male header | 1 | 7-pin aircraft interface connector; or cut from 40-pin strip |
| J2 | 1×10 2.54mm male header | 1 | 10-pin panel unit connector; or cut from 40-pin strip |
| PS1 | 1×5 2.54mm male header | 1 | 5-pin for LM2596 module |
| — | 40-pin 2.54mm male header strip | 1 | Break-apart; covers J1/J2/PS1 (22 pins needed) |

**Tip:** Buy a 40-pin break-apart header strip and a 40-pin female socket strip on Amazon (~$1 each). These cover all connector needs on the board.

---

## Panel Unit Components

| Part | Qty | Est. Cost | Notes |
|---|---|---|---|
| 5-position rotary switch | 1 | $8–15 | **Single-pole, 5-position.** Lorlin CK1024 or Grayhill 56-series. Must have positive detents (not a continuous encoder). Panel-mount with standard ¼" shaft. |
| Project enclosure or panel plate | 1 | $5–15 | Size depends on your panel opening. Aluminum preferred. |
| Multi-conductor shielded cable | ~3 ft | $5–10 | 10 conductors sufficient. Belden 9536 or equivalent avionics-grade cable. |

**Switch selection notes:**
- Lorlin CK1024: 12-position base type, order 5-position variant. Available Mouser/Digi-Key. ~$8.
- Grayhill 56-series: industry-standard panel switch, very positive detent feel, standard ¼" D-shaft. ~$12–15.
- Avoid: continuous rotary encoders (no detents), wafer switches without detents, or switches with more than 5 positions (firmware only uses 5).
- The original prop control knob reuses directly on any ¼" D-shaft switch.

---

## Aircraft Interface

| Part | Qty | Source | Notes |
|---|---|---|---|
| 7-pin Cannon/MS connector (plug) | 1 | Aircraft Spruce, B&C Specialty, Stein Air | MS3106A-16-10S or equivalent. Match to existing connector on airframe. **Measure yours first.** ~$15–40 |
| Backshell for connector | 1 | Same sources | Strain relief; important for vibration environment |
| 22 AWG shielded wire | ~2 ft | Aircraft Spruce or local | For magneto lead connection inside governor box |
| Heat shrink tubing assortment | 1 | — | Cover all solder connections |
| Aluminum project box | 1 | Hammond Mfg or similar | Size your own governor box; original dimensions ~85×65×30mm |

---

## Tools Required (not included in cost estimate)

- Temperature-controlled soldering iron
- Multimeter
- Flush cutters
- Arduino IDE (free download)
- USB-A cable for programming Nano
- Oscilloscope (recommended but optional)
- Second Arduino Nano for bench test pulse generator (~$5 extra)

---

## Complete Order Summary

### Digi-Key single order (all board passives + ICs):
6N137 × 1, 2N2907A × 2, 2N2222A × 2, 1N4001 × 2, 10kΩ resistor × 4 (R1/R7/R8 + spare), 4.7kΩ × 1, 1kΩ × 2, 330Ω × 2, 100nF cap × 3, 100µF 25V cap × 1, 47µF 10V cap × 1, DIP-8 socket × 1

**Estimated Digi-Key subtotal: ~$14–20**

### Amazon or eBay (modules and panels):
Arduino Nano × 1, LM2596-5V module × 1, SSD1306 OLED 1.3" × 1, LED assortment (red + green 3mm) × 1, pin header strips × 1, female socket strips × 1, 1A PTC fuse × 1

**Estimated Amazon subtotal: ~$18–28**

### Mouser or Digi-Key (rotary switch):
5-position rotary switch (Lorlin CK1024 or Grayhill 56-series) × 1

**Estimated switch cost: ~$8–15**

### Aircraft Spruce or B&C (aircraft hardware):
7-pin Cannon connector and backshell, avionics wire

**Estimated aircraft hardware: ~$20–45**

### JLCPCB:
5× PCBs + shipping (typically $2 boards + $8–15 shipping to US)

**Estimated PCB: ~$10–17**

---

## Notes on Substitutions

**Arduino Nano:** The CH340 USB chip version is fine. Avoid:
- Arduino Nano Every (different pinout)
- Arduino Nano 33 IoT / BLE (3.3V logic — relay drive levels won't work)
- Any 3.3V variant

**6N137 optocoupler:** Do not substitute with slower optocouplers (4N25, 4N35, PC817). The magneto signal at cruise RPM is ~130 Hz and the pulse width matters. The 6N137 has 10ns response time — slower types will miss pulses or distort the signal.

**2N2907A (Q1, Q2):** TO-92L package (also called TO-226 or TO-92 wide). The 2N2907A is available in TO-18 (metal can) and TO-92L (plastic). The PCB footprint is TO-92L — do not install the metal can TO-18 variant. Pin order is EBC (Emitter-Base-Collector) from left to right when facing the flat side.

**2N2222A (Q3, Q4):** Standard TO-92 package. Very common; any major supplier. Pin order is EBC. Do not substitute 2N2219 (TO-39 metal can) — wrong footprint.

**1N4001 (D3, D4):** Any 1N400x series (1N4001 through 1N4007) works here; the voltage rating doesn't matter in this application. Observe polarity — cathode (banded end) to the +12V rail.

**LM2596 module:** Must be the fixed 5V version. The adjustable version ships set to ~12V and will destroy the Nano if installed without adjusting first. The fixed 5V version has a yellow label; the adjustable has a blue trimmer. Buy the fixed 5V version or verify before installing.

**OLED display:** If display shows garbage on boot, the I2C address is 0x3D not 0x3C. Change one line in firmware and reflash. Both addresses are common among different module batches.

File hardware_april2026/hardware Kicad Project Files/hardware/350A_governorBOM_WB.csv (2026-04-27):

Id | Designator | Footprint | Quantity | Designation | Supplier and ref
1 | A1 | Arduino_Nano | 1 | Arduino_Nano
2 | C1, C4, C5 | C_Disc_D3.8mm_W2.6mm_P2.50mm | 3 | 100nF
3 | C2 | CP_Radial_D5.0mm_P2.50mm | 1 | 100uF/16V
4 | C3 | CP_Radial_D5.0mm_P2.50mm | 1 | 47uF/10V
5 | D1 | LED_D3.0mm | 1 | LED_RED
6 | D2 | LED_D3.0mm | 1 | LED_GRN
7 | D3, D4 | D_DO-15_P12.70mm_Horizontal | 2 | D_DO-15_P12.70mm_Horizontal
8 | F1 | Fuse_BelFuse_0ZRE0012FF_L8.3mm_W3.8mm | 1 | Fuse_BelFuse_0ZRE0012FF_L8.3mm_W3.8mm
9 | J1 | PinHeader_1x07_P2.54mm_Vertical | 1 | CANNON_7PIN
10 | J2 | PinHeader_1x10_P2.54mm_Vertical | 1 | PANEL_10PIN
11 | PS1 | PinHeader_1x05_P2.54mm_Vertical | 1 | LM2596-5V
12 | Q1, Q2 | TO18 | 2 | TO18
13 | Q3, Q4 | TO92254P470H750-3 | 2 | TO92254P470H750-3
14 | R1, R5, R6, R7, R8 | R_Axial_DIN0207_L6.3mm_D2.5mm_P7.62mm_Horizontal | 5 | 10k
15 | R2 | R_Axial_DIN0207_L6.3mm_D2.5mm_P7.62mm_Horizontal | 1 | 4k7
16 | R3, R4 | R_Axial_DIN0207_L6.3mm_D2.5mm_P7.62mm_Horizontal | 2 | 330R
17 | U1 | DIP-8_W7.62mm | 1 | 6N137

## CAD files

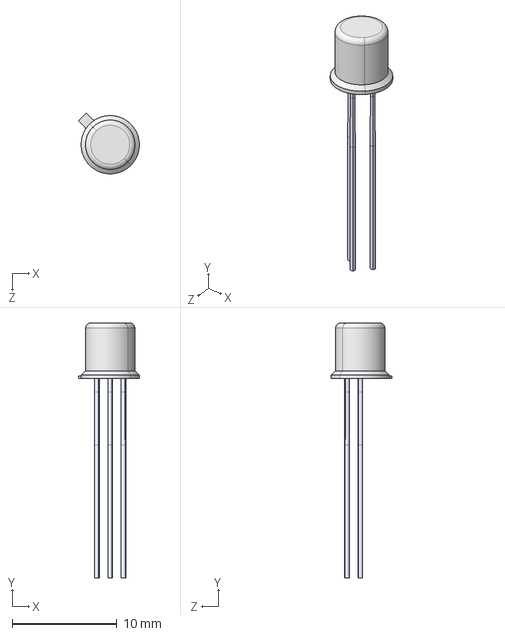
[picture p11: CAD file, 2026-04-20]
hardware_rev3_1/hardware/2N2222A/2N2222A.step
5.80 x 24.4 x 5.80 mm

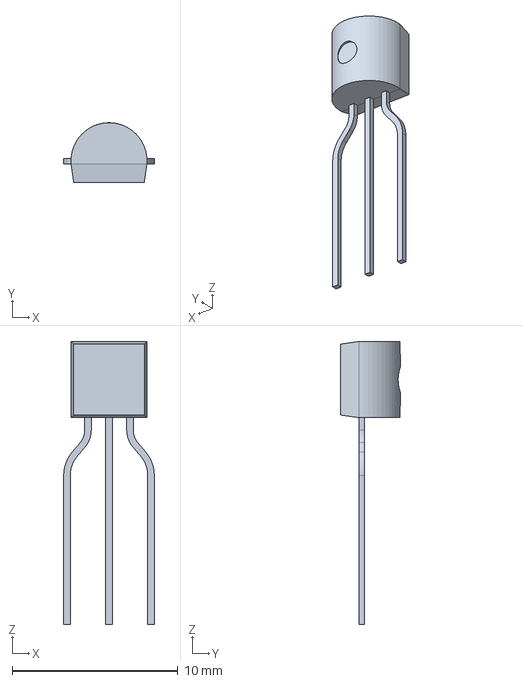
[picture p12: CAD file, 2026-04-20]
hardware_rev3_1/hardware/2N2907A_/2N2907A_.step
5.48 x 3.60 x 17.1 mm

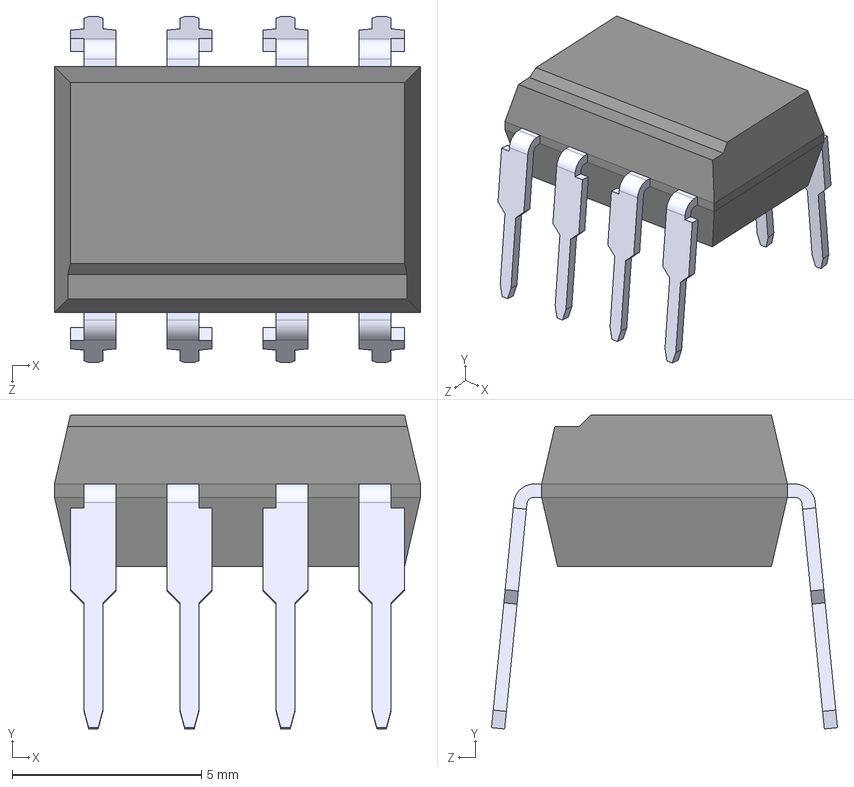
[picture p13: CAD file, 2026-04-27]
hardware_rev3_1/hardware/6N137/6N137.step
9.68 x 8.30 x 9.15 mm

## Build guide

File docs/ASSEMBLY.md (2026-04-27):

# Assembly Instructions

## Overview

This guide covers the complete build from bare PCB to installed system. Estimated time for an experienced solderer: 3–4 hours for the governor PCB, 1 hour for the panel unit. First-time builders should budget a full day and not rush.

**Skill level required:** Basic soldering. All components are through-hole — no SMD. If you've built a kit before, you can build this.

---

## Tools Required

- Temperature-controlled soldering iron (650–700°F / 340–370°C)
- 60/40 or 63/37 rosin-core solder, 0.031" diameter
- Flush cutters (lead trimmers)
- Digital multimeter
- Small Phillips and flat screwdrivers
- Tweezers
- Magnifying glass or loupe
- Isopropyl alcohol (90%+) and brush for flux cleanup
- Arduino IDE installed on a computer with USB-A port

**Recommended but not required:**
- PCB holder / helping hands
- Desoldering braid (for mistakes)
- Continuity tester (your multimeter in beep mode)

---

## Parts Checklist

Verify all parts against [BOM.md](../hardware/BOM.md) before starting. Lay them out and identify each one. The most common build error is swapping similar-looking components (e.g., installing a 330Ω where a 10kΩ belongs). Resistor color bands are your friend — confirm each one with your multimeter before soldering.

---

## Section 1: PCB Preparation

### 1.1 Inspect the Board

When your JLCPCB boards arrive (you'll receive 5 — use one, keep the rest):

- Check for any obvious defects: scratches through copper traces, missing pads, solder bridges from fabrication
- Hold it up to light and look for pinholes in the FR4 (rare but check)
- Verify the board dimensions are 100mm × 80mm
- Confirm 4 mounting holes in the corners

### 1.2 Production Gerbers

The Gerbers in `hardware/gerbers/350A_governor_JLCPCB.zip` are ready to upload to JLCPCB. They were generated from the current V3 PCB with copper zones filled and 0 DRC violations — no additional KiCad steps are required before ordering.

---

## Section 2: Governor PCB Assembly

**Assembly order matters.** Always install lowest-profile components first so the board lies flat while soldering subsequent components.

### 2.1 Resistors (install first — lowest profile)

| Ref | Value | Color Code | Location |
|---|---|---|---|
| R1 | 10kΩ | Brn-Blk-Org-Gold | Magneto input current limit |
| R2 | 4.7kΩ | Yel-Vio-Red-Gold | Optocoupler pull-up |
| R3 | 330Ω | Org-Org-Brn-Gold | INC LED current limit |
| R4 | 330Ω | Org-Org-Brn-Gold | DEC LED current limit |
| R5, R6 | 1kΩ | Brn-Blk-Red-Gold | NPN base resistors (Q3, Q4) |
| R7, R8 | 10kΩ | Brn-Blk-Org-Gold | PNP base pull-ups (Q1, Q2) |

Resistors are non-polarized — orientation doesn't matter. Bend leads at 90°, insert, tape or bend leads slightly to hold in place, solder, trim leads flush.

**Verify each with your multimeter before soldering.**

### 2.2 Ceramic Capacitors (non-polarized, install next)

| Ref | Value | Marking | Notes |
|---|---|---|---|
| C1 | 100nF | 104 | Magneto noise bypass |
| C4 | 100nF | 104 | VIN_5V supply bypass |
| C5 | 100nF | 104 | 5V supply bypass |

Ceramic caps are non-polarized. The "104" marking means 10 × 10⁴ pF = 100nF = 0.1µF. These are all the same part.

### 2.3 Electrolytic Capacitors (POLARIZED — observe polarity)

| Ref | Value | Location | Notes |
|---|---|---|---|
| C2 | 100µF / 25V | LM2596 input | Longer lead = POSITIVE. Stripe on body = NEGATIVE. |
| C3 | 47µF / 10V | LM2596 output | Same polarity convention. |

⚠️ **Electrolytic capacitors installed backwards will fail, possibly violently.** The PCB has a "+" marking on the positive pad. The longer lead goes to "+". The stripe on the capacitor body marks the NEGATIVE lead.

### 2.4 LEDs (POLARIZED)

| Ref | Color | Notes |
|---|---|---|
| D1 | Red | INC RPM activity indicator |
| D2 | Green | DEC RPM activity indicator |

LEDs are polarized. The **longer lead is the anode (+)**. The flat side of the LED body is the cathode (−). The PCB silkscreen shows a triangle pointing toward a bar — the bar is the cathode.

Install these so the lens is just above the PCB surface. Do not push them all the way flush — they will be visible indicators during testing.

### 2.5 Transistors (Q1–Q4)

The relay driver circuit uses two NPN+PNP transistor pairs — all TO-92 package, about the same size as a small LED.

| Ref | Part | Type | Notes |
|---|---|---|---|
| Q1, Q2 | 2N2907A | PNP — high-side switch | TO-92L (wide body). Switches +12V to relay coil. |
| Q3, Q4 | 2N2222A | NPN — level shifter | Standard TO-92. Driven by Nano D6/D7 (5V logic). |

**Pin orientation (critical):** Facing the flat side of the TO-92 body, pin order is **E – B – C** left to right for both types. The PCB silkscreen shows the flat body side — match it.

**2N2907A package note:** The PCB footprint is TO-92L (wide/plastic body). Do not use the TO-18 metal-can variant — the lead spacing is incompatible.

### 2.6 Protection Diodes and Fuse

| Ref | Part | Notes |
|---|---|---|
| D3, D4 | 1N4001 | Flyback diodes — **cathode (banded end) toward +12V**. Clamps relay coil inductive spikes. Do not omit. |
| F1 | 1A PTC fuse | In series with 12V_RAW input. Self-resets after overcurrent. Observe orientation per silkscreen. |

⚠️ **D3/D4 polarity:** Cathode (silver band) goes toward the +12V_RAW side of each relay coil pad. Reversed diodes do not protect the transistors from inductive kickback.

### 2.7 IC Sockets (install before ICs)

**Install sockets, not the ICs directly.** This allows replacement without desoldering.

| Ref | Socket | Notes |
|---|---|---|
| U1 | DIP-8 socket | For 6N137 optocoupler |

Align the notch on the socket with the notch shown on the PCB silkscreen. Solder one corner pin first, verify alignment, then solder remaining pins.

### 2.8 Connectors and Headers

Install these before the Arduino socket — they need the iron to get in from the sides.

**J1 — 7-pin Governor Cannon Interface Header:**
- 1×7 2.54mm pin header
- This is the most critical connector on the board — carries 12V, relay outputs, and the magneto signal
- Solder with care; cold joints here will cause intermittent failures
- Label: A B C D E F H (per silkscreen)

**PS1 — LM2596 Module Header:**
- 1×5 2.54mm pin header
- The LM2596 breakout module plugs in here

**J2 — Panel Connector (10-pin):**
- 1×10 2.54mm pin header or socket
- Connects to the panel unit cable

### 2.9 Arduino Nano Socket

Use two 15-pin female socket strips (or a 30-pin strip cut in half). This lets you remove the Nano for firmware updates without disturbing the installation.

- Install female sockets on the PCB pads
- The Nano plugs in from above
- Verify orientation: the USB port end of the Nano faces toward the top of the board (toward J1)

### 2.10 IC Installation

Once all soldering is complete and you've done the pre-power inspection (Section 4.1):

- **U1 (6N137):** Align pin 1 (notch end) with pin 1 on socket. Press firmly and evenly.

### 2.11 LM2596 5V Module

The LM2596S-5V is a pre-built DC-DC converter module. It should arrive pre-set to 5V output, but **verify this before plugging it in** (see Section 4.2).

Plug into PS1 header. The module sits about 10mm above the PCB.

### 2.12 Arduino Nano

Flash the firmware BEFORE installing in the board (easier to handle). See Section 3.

---

## Section 3: Firmware

### 3.1 Install Arduino IDE

Download Arduino IDE 2.x from arduino.cc. Install the CH340 driver if on Windows (the Nano uses a CH340 USB-serial chip — Windows needs this driver; Mac and Linux usually don't).

### 3.2 Install Required Libraries

In Arduino IDE, go to Tools → Manage Libraries and install:
- **Adafruit SSD1306** (by Adafruit)
- **Adafruit GFX Library** (by Adafruit, will be installed as a dependency)

### 3.3 Configure Firmware Constants

Open `firmware/governor_350A/governor_350A.ino`. At the top of the file, find the configuration section and set:

```cpp
// ── CRITICAL: Set for your engine ──────────────────────────────
#define PULSES_PER_REV  3    // 6-cyl Continental (IO-470, IO-520, E-185/E-225)
                             // Change to 2 for 4-cylinder engines

// ── Preset RPM targets ─────────────────────────────────────────
#define PRESET_MAX          2650   // Full fine pitch / takeoff
#define PRESET_CRUISE_CLIMB 2450   // Best-power climb
#define PRESET_CRUISE       2300   // Normal cruise (default on AUTO engage)
#define PRESET_ECONOMY      2200   // Long-range economy
// Preset 5 (Emergency/Low) drives to full coarse limit — no RPM target

// ── Control tuning ─────────────────────────────────────────────
#define DEADBAND_RPM        25     // No correction within ±25 RPM of setpoint
#define PROP_ZONE_RPM       75     // Proportional slowdown begins within ±75 RPM
#define MAG_TIMEOUT_MS      2000   // Alarm if no magneto pulse for 2 seconds
#define MAX_RELAY_MS        8000   // Safety cutoff: max relay on-time in ms
```

### 3.4 Flash

1. Connect Nano via USB
2. Tools → Board → Arduino AVR Boards → Arduino Nano
3. Tools → Processor → ATmega328P (Old Bootloader) — try this if standard doesn't work
4. Tools → Port → select the COM port / /dev/ttyUSBx that appeared when you plugged in
5. Click Upload (→ arrow)
6. Confirm "Done uploading" — no errors

### 3.5 Verify Firmware on Bench

With the Nano connected by USB and powered (no aircraft connection yet):
- The OLED should light up showing "MANUAL" mode
- Rotating the encoder should not change anything in MANUAL
- Pressing a preset button should change the setpoint display but not engage AUTO
- No fault codes should be showing

---

## Section 4: Pre-Power Inspection

Before applying any power, perform these checks.

### 4.1 Visual Inspection

- All leads trimmed flush — no solder bridges between adjacent pads
- No flux residue (clean with IPA and brush if needed)
- All ICs seated correctly in sockets with pin 1 aligned to notch
- Electrolytic capacitors: positive lead to "+" pad, stripe away from "+" pad
- LED polarity confirmed

### 4.2 LM2596 Output Voltage Verification

**Do this BEFORE plugging the module into the board.**

1. Set your bench supply to 12–14V (simulating aircraft bus)
2. Apply 12V to the LM2596 module input pins (VIN and GND)
3. Measure output voltage between VOUT and GND pins
4. Should read 5.0V ±0.2V
5. If not 5V, adjust the small trimmer pot on the module until it reads 5.0V

Applying unregulated 12V to the Nano's 5V pin will destroy it. This step is not optional.

### 4.3 Continuity Checks

With no power applied, use your multimeter in continuity/beep mode:

| Test | Expected |
|---|---|
| J1 pin B (GND) to any ground pad | Continuity (beep) |
| J1 pin A (12V) to GND | No continuity (no beep — no dead short) |
| J1 pin C (INC) to GND | No continuity |
| J1 pin D (DEC) to GND | No continuity |
| 5V rail to GND | No continuity (small resistance OK, direct short = problem) |

---

## Section 5: Bench Power Test

### 5.1 First Power Application

Use a current-limited bench supply set to 13.8V / 500mA current limit.

1. Do NOT connect the aircraft Cannon connector yet
2. Apply 12V to J1 pin A and ground to J1 pin B using clip leads
3. Current draw should be 50–150mA (OLED + Nano idle)
4. If current limit trips immediately: **power off and find the short**

### 5.2 Voltage Rail Verification

With power applied:
| Test point | Expected |
|---|---|
| LM2596 output | 5.0V ±0.1V |
| Nano Vin pin | 5.0V |
| Nano 5V pin | ~4.9–5.0V |
| Nano 3.3V pin | 3.3V |

### 5.3 OLED Display Check

The OLED should be showing the startup screen. If blank:
- Check I2C address — SSD1306 modules ship at either 0x3C or 0x3D. The firmware defaults to 0x3C. If blank, edit `#define OLED_I2C_ADDR 0x3C` to `0x3D` and reflash.
- Check the J2 connector — confirm SDA (pin 3) and SCL (pin 4) are wired to Nano A4 and A5

---

## Section 6: Panel Unit Assembly

The panel unit mounts in the existing prop control knob opening on the instrument panel.

### 6.1 Components

- SSD1306 1.3" OLED module (I2C, 128×64)
- 5-position single-pole rotary switch (Lorlin CK1024 or Grayhill 56-series recommended)
- Small panel plate or project enclosure

### 6.2 Layout Suggestion

```
┌─────────────────────────────────────────────┐
│  [OLED DISPLAY — 1.3"]                      │
│  CRUISE                              AUTO   │
│  CRUISE                                     │
│  ─────────────────────────────              │
│  SET: 2300 RPM                              │
│  ACT: 2287 RPM                              │
│  HOLD ──────────────────                    │
├─────────────────────────────────────────────┤
│         MAX  CLB  CRS  ECO  LOW             │
│        [ 1 - 2 - 3 - 4 - 5 ]               │
│              [  KNOB  ]                     │
└─────────────────────────────────────────────┘
```

The 5-position rotary switch provides tactile, positive detent selection of each preset. There is no ambiguous "between" state in normal use — each detent corresponds to a specific RPM.

### 6.3 Rotary Switch Wiring

The switch has one COMMON terminal and five position terminals:

```
Switch COMMON  ──── GND  (J2 pin 2 or pin 10)
Position 1     ──── J2 pin 5  (MAX 2650)
Position 2     ──── J2 pin 6  (CRUISE CLIMB 2450)
Position 3     ──── J2 pin 7  (CRUISE 2300)
Position 4     ──── J2 pin 8  (ECONOMY 2200)
Position 5     ──── J2 pin 9  (LOW/EMERGENCY COARSE)
```

No resistors needed. The Nano's internal pull-ups (activated in firmware) keep all position lines HIGH. The selected position pulls its line LOW through the switch.

### 6.4 Panel Cable

10-conductor shielded cable, J2 connector at both ends (or bare wires at the switch end). Total wires: 5V, GND, SDA, SCL, positions 1–5, switch common = 10. The original installation's cable routing can be reused.

### 6.5 Reusing the Original Knob

The original prop control knob fits any ¼" D-shaft rotary switch. The Lorlin CK1024 and Grayhill 56-series both use standard ¼" shafts. If the original knob has a different bore, knob adapters are available from Mouser for ~$1.

---

## Section 7: Bench Test with Motor

See [BENCH_TEST.md](BENCH_TEST.md) for the complete bench test procedure using a pulse generator Arduino and your spare prop motor.

**Do not install in the aircraft until bench testing is complete and you are satisfied with operation.**

---

## Section 8: Aircraft Installation

**Have your IA present for the aircraft installation.**

### 8.1 Remove the Original 350A

1. Aircraft master OFF, magneto OFF
2. Disconnect the 7-pin Cannon connector from the 350A
3. Remove the four screws securing the 350A to its mounting spacers
4. Note the orientation — the new unit mounts the same way (connector facing down, nameplate facing cabin door)

### 8.2 Mount the New Governor Box

1. Mount the PCB in a suitable enclosure (the original die-cast box can be reused if dimensions fit, or a new aluminum project box)
2. Drill for the 7-pin Cannon connector pass-through
3. Mount on the original spacers using the same 4 screws
4. Connect the Cannon connector — verify locking ring engages

### 8.3 Install the Panel Unit

1. Remove the original prop control knob assembly
2. Feed the panel unit cable through the control column per the original cable routing
3. Install the panel unit in the knob opening
4. Route cable clear of all control cables and moving parts — secure with tie wraps
5. The original knob can be reused on the new linear pot shaft

### 8.4 Ground Test Before First Flight

Follow the Ground Test section of the original 350A manual (reproduced in the firmware comments and in [BENCH_TEST.md](BENCH_TEST.md)). The key test:

1. Engine running at 1900 RPM
2. Prop switch to AUTO
3. Turn RPM knob full CW and CCW — observe RPM changes
4. Note: *some oscillation at low RPM on the ground is normal* — the prop aerodynamics are fundamentally different at low ground RPM than in flight. Do not tune for ground performance.

### 8.5 First Flight Test

1. Takeoff and climb in MANUAL — as normal
2. At safe altitude, level off at cruise power
3. Select CRUISE preset (2300)
4. Engage AUTO
5. Observe: RPM should stabilize within 3–5 corrections
6. Make small throttle inputs and verify governor compensates smoothly
7. If hunting is excessive, increase DEADBAND_RPM in firmware (try 35, then 50) and reflash

---

## Torque Values and Hardware Notes

| Fastener | Torque |
|---|---|
| Governor mounting screws (original spacers) | Finger tight + 1/4 turn |
| Cannon connector locking ring | Hand tight |
| Panel pot shoulder nut | 24 inch-pounds (per original 350A spec) |

---

## Revision History

| Rev | Date | Changes |
|---|---|---|
| 1.0 | Initial release | First production version |
| 3.0 | 2026-04-27 | V3 PCB: ULN2003A (U2) replaced by discrete NPN+PNP transistor pairs (Q1–Q4); added flyback diodes D3/D4 and PTC fuse F1; J3 removed; C3 changed to 10V rating; added R5–R8 |

---

*Questions? Open an issue on GitHub. Include your aircraft serial number range (early/late wiring variant matters), engine model, and a description of what you observe.*

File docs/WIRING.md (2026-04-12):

# Wiring Reference

## 7-Pin Governor Cannon Connector (J1)

This is the aircraft-side connector. **Pinout is identical to the original 350A.** No aircraft wiring changes are required.

| Pin | Letter | Signal | Wire Color (typical) | Description |
|---|---|---|---|---|
| 1 | A | 12V_RAW | Red | Aircraft bus through prop circuit breaker and AUTO/OFF switch |
| 2 | B | GND | Black/Green | Airframe ground |
| 3 | C | INC_RELAY | Varies | 12V output: energizes INC RPM relay (fine pitch / increase RPM) |
| 4 | D | DEC_RELAY | Varies | 12V output: energizes DEC RPM relay (coarse pitch / decrease RPM) |
| 5 | E | POT_END_1 | Varies | One end of panel rheostat/potentiometer |
| 6 | F | POT_END_2 | Varies | Other end of panel rheostat/potentiometer |
| 7 | H | MAG_P_LEAD | White | Right magneto P-lead (through 10kΩ isolating resistor in governor) |

**Note on pins E and F:** In the original installation these are the two ends of the panel rheostat. In the rotary switch implementation, pin E carries GND to the panel (switch COMMON). Pin F is spare. The 10-wire J2 panel cable handles all panel unit connections directly without needing J1 pins E/F for signal routing.

---

## Panel Unit to PCB Cable (J2 — single connector)

A single 10-conductor shielded cable connects the panel unit to the governor box. The rotary switch replaces the original pot, 5 buttons, and encoder — **10 wires does the whole job.**

### J2 — 10-pin Panel Connector

| Pin | Signal | Panel Connection |
|---|---|---|
| 1 | +5V | OLED VCC |
| 2 | GND | OLED GND, switch common (both tie here) |
| 3 | SDA | OLED I2C data |
| 4 | SCL | OLED I2C clock |
| 5 | SW_POS1 | Switch position 1 terminal (MAX 2650) |
| 6 | SW_POS2 | Switch position 2 terminal (CRUISE CLIMB 2450) |
| 7 | SW_POS3 | Switch position 3 terminal (CRUISE 2300) |
| 8 | SW_POS4 | Switch position 4 terminal (ECONOMY 2200) |
| 9 | SW_POS5 | Switch position 5 terminal (LOW/EMERGENCY COARSE) |
| 10 | SW_COMMON | Switch COMMON terminal (ties to GND at panel or at PCB) |

**Switch wiring principle:** The rotary switch COMMON terminal is connected to GND (pin 10 / pin 2). Each position terminal goes to its respective signal wire (pins 5–9). Internal pull-ups in the Nano keep all signal lines HIGH; whichever position is selected pulls its line LOW through the switch. No external resistors needed anywhere in the switch circuit.

**Note on SW_COMMON:** Pin 10 and Pin 2 are both GND — you can tie the switch common directly to pin 2 at the panel connector if that's easier, and leave pin 10 unused. The separate pin 10 just makes the wiring cleaner.

---

## Arduino Nano Pin Assignment

| Nano Pin | Function | Direction | Notes |
|---|---|---|---|
| D2 | RPM_PULSE | Input | 6N137 optocoupler output; hardware interrupt INT0 |
| D3 | SW_POS1 | Input | Rotary switch position 1 (MAX 2650); internal pull-up |
| D4 | SW_POS2 | Input | Rotary switch position 2 (CRUISE CLIMB 2450); internal pull-up |
| D5 | SW_POS3 | Input | Rotary switch position 3 (CRUISE 2300); internal pull-up |
| D6 | INC_RELAY_DRIVE | Output | To PNP transistor base (via 1kΩ); high-side switches +12V to INC relay coil |
| D7 | DEC_RELAY_DRIVE | Output | To PNP transistor base (via 1kΩ); high-side switches +12V to DEC relay coil |
| D8 | INC_LED | Output | Red LED via 330Ω; INC activity indicator |
| D9 | DEC_LED | Output | Green LED via 330Ω; DEC activity indicator |
| D10 | SW_POS4 | Input | Rotary switch position 4 (ECONOMY 2200); internal pull-up |
| D11 | SW_POS5 | Input | Rotary switch position 5 (LOW/EMERGENCY COARSE); internal pull-up |
| D12 | (spare) | — | Available for future use |
| A0 | (spare) | — | Available for future use |
| A1 | (spare) | — | Available for future use |
| A4 | SDA | I2C | OLED display data (Wire library) |
| A5 | SCL | I2C | OLED display clock (Wire library) |
| VIN | 5V_INPUT | Power | From LM2596 5V output |
| GND | GND | Power | Multiple ground connections |

---

## Aircraft Wiring Variants (Early vs. Late Models)

The Bonanza had a wiring change at serial number D-1821. This affects how the prop motor relays are connected and whether the limit switches are in the control loop.

### Early Models (Serial Numbers through D-1820)

- The prop control switch energizes relays when moved to INC or DEC position
- Relays supply voltage to the pitch change motor
- Limit switches are in the relay coil circuit (in some configurations)
- The governor (original or replacement) commands the relays through the same switch

**Symptom if you have the early wiring:** If MANUAL operation works but AUTO does nothing, verify relay operation per the original 350A Service Note 1 (Airframe Systems Test).

### Later Models (Serial Numbers D-1821 and On)

- Panel switch supplies motor current directly (no relay for manual operation)
- Relays handle only the automatic (governor) function
- Simpler and more reliable for automatic operation
- Relay failure affects only AUTO mode, not MANUAL

**To determine which wiring you have:** With engine OFF, master ON, move prop switch to INC or DEC. If motor stops at pitch extremes (limit switches working), you likely have early wiring. If motor continues at pitch extremes making a clicking sound, you have late wiring or the limit switches are bypassed.

See the original 350A Service Note 9 (MANUAL WIRING) and Figures C and D in the original documentation for schematic details.

---

## Limit Switch Wiring

The full fine and full coarse limit switches live in the prop hub and connect through the slip ring assembly. Their wires emerge from the rear of the prop hub. They are in series with the relay contacts — when a limit is reached, the switch opens and the motor stops regardless of what the governor commands.

| Limit | Switch State (at limit) | Effect |
|---|---|---|
| Full Fine Pitch | Open | Prevents further INC RPM commands from running motor |
| Full Coarse Pitch | Open | Prevents further DEC RPM commands from running motor |

**After prop overhaul:** The limit switch wires are occasionally reconnected backwards at the prop during reinstallation. See original 350A Service Note 1, Step 8 for the diagnostic. Symptom: prop goes to coarse instead of fine when INC is commanded, or vice versa.

---

## Signal Levels

| Signal | Level | Notes |
|---|---|---|
| 12V supply | 11–15V | Aircraft battery/alternator bus; tolerant of normal variation |
| Magneto P-lead | 0–12V | Coil fires produce brief ground pulses; rest state is ~12V |
| Relay drive (C, D) | 0V or 12V | Bang-bang for large errors; time-proportioned in proportional zone |
| 5V logic (Nano, OLED, optocoupler) | 5.0V ±5% | Generated by LM2596 from aircraft bus |
| I2C bus (SDA, SCL) | 0–5V | 400kHz fast-mode; 4.7kΩ pull-ups on each line |
| ADC input (pot wiper) | 0–5V | Linear across 0–10kΩ pot sweep; 50-sample averaged |

---

## Pinout Cross-Reference: Original 350A vs. New Board

For IAs doing the 337 review, this table shows the complete equivalence of the external interface:

| Original 350A Pin | Original Function | New Board Pin | New Function | Equivalent? |
|---|---|---|---|---|
| A | 12V supply input | J1-A | 12V_RAW | ✓ Identical |
| B | Airframe ground | J1-B | GND | ✓ Identical |
| C | INC RPM relay coil drive | J1-C | INC_RELAY_DRIVE | ✓ Equivalent — see note below |
| D | DEC RPM relay coil drive | J1-D | DEC_RELAY_DRIVE | ✓ Equivalent — see note below |
| E | Rheostat end 1 | J1-E | SW_COMMON (GND) | ✓ Functionally equivalent — switch common replaces rheostat end; GND is carried to panel |
| F | Rheostat end 2 | J1-F | Spare / NC | ✓ Pin present; unused in rotary switch implementation |
| H | Magneto P-lead sense | J1-H | MAG_P_LEAD (through 10kΩ isolator) | ✓ Identical; isolator preserved |

The relay coil loads (current draw on C and D) are identical. The magneto input impedance is identical (10kΩ isolating resistor preserved in the new design). The power supply loading on pin A is lower (switching regulator vs. linear), which is a improvement. No airframe wiring changes are needed or permitted without additional 337 documentation.

**Note on J1-C and J1-D relay drive polarity:** The original 350A is a **high-side driver** — it switches +12V onto pins C and D to energize the relay coils. The relay circuits in the aircraft are wired with the coil's cold side grounded through the pitch-limit switches, so the hot side (+12V) must be switched by the governor. The new board uses **PNP transistors** (one per relay channel) as high-side switches, providing the same +12V-switched output on J1-C and J1-D. The NPN ULN2003A Darlington array found in many Arduino relay tutorials is **not compatible** with this wiring — it provides a ground-side switch, which is the wrong topology for this circuit.

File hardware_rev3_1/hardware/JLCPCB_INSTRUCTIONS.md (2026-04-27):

# Ordering the PCB — JLCPCB

The board is fully routed. Use the Gerber zip in the `pcbway_production/` folder to order.

## Steps

1. Open [jlcpcb.com](https://jlcpcb.com) and click **Order Now**
2. Upload `gerbers/350A_governor_JLCPCB.zip`
3. Confirm the settings below and add to cart

## JLCPCB Settings

| Setting | Value |
|---|---|
| Layers | 2 |
| Dimensions | 100 × 80 mm (auto-detected) |
| PCB Thickness | 1.6 mm |
| Surface Finish | HASL (with lead) |
| Copper Weight | 1 oz |
| Everything else | Default |

You receive 5 boards per order; use 1, keep the rest as spares.

## If You Need to Regenerate Gerbers

Open `350A_governor.kicad_pcb` in KiCad 10, then:

1. **Edit → Fill All Zones**
2. **Inspect → Design Rules Checker** — confirm 0 errors before proceeding
3. **File → Fabrication Outputs → Gerbers**
   - Layers: F.Cu, B.Cu, F.Mask, B.Mask, F.Silkscreen, Edge.Cuts
4. **File → Fabrication Outputs → Drill Files**
5. Zip the output folder and upload

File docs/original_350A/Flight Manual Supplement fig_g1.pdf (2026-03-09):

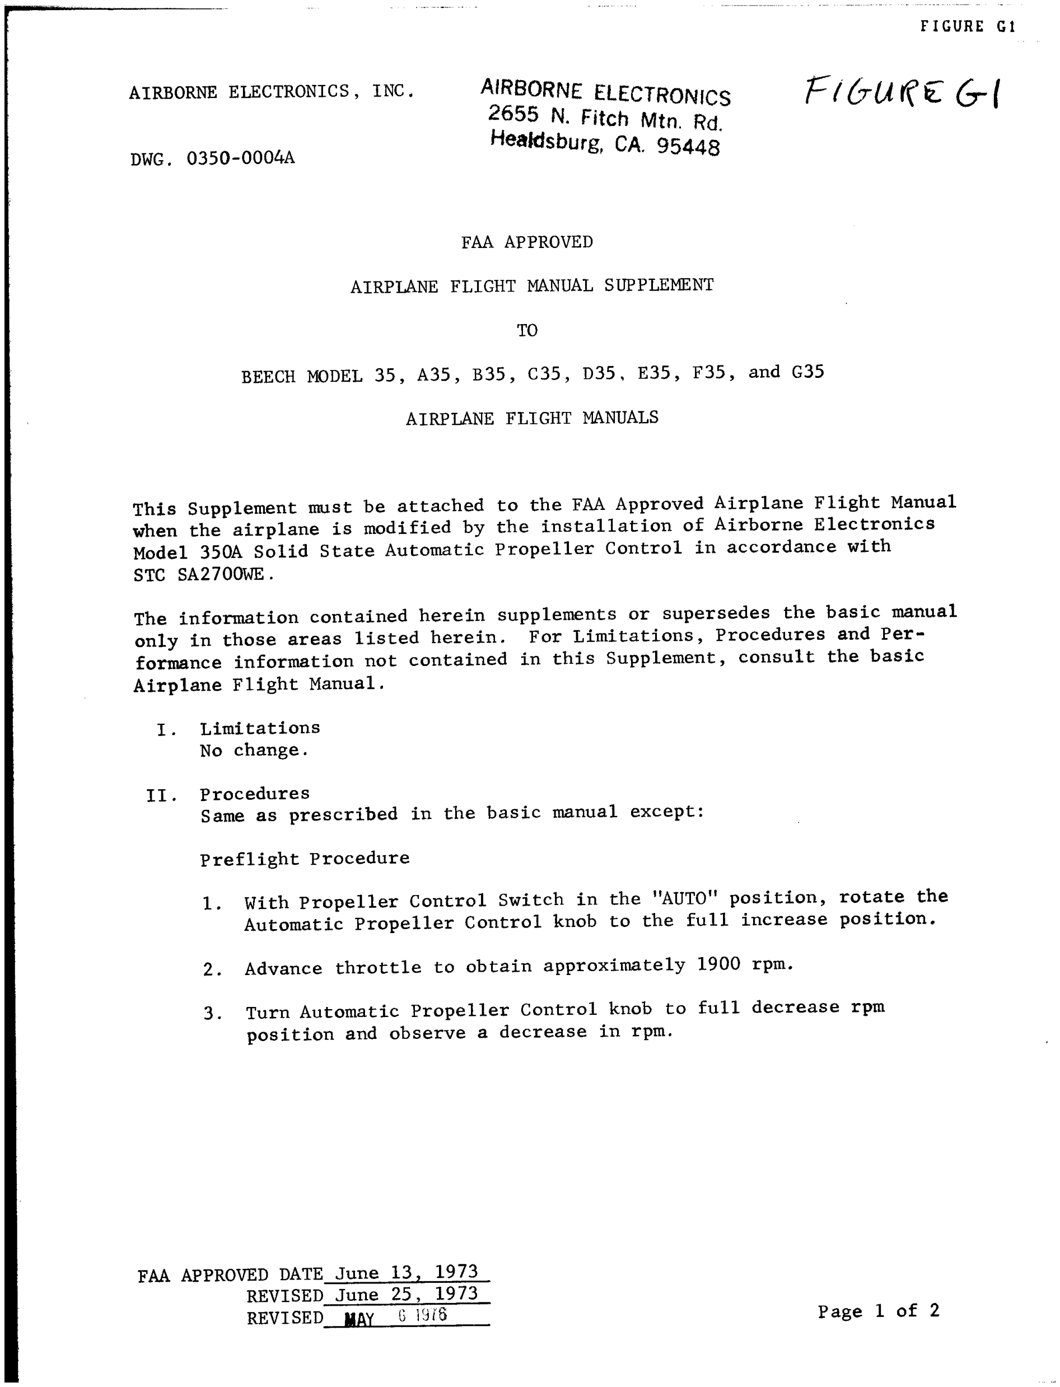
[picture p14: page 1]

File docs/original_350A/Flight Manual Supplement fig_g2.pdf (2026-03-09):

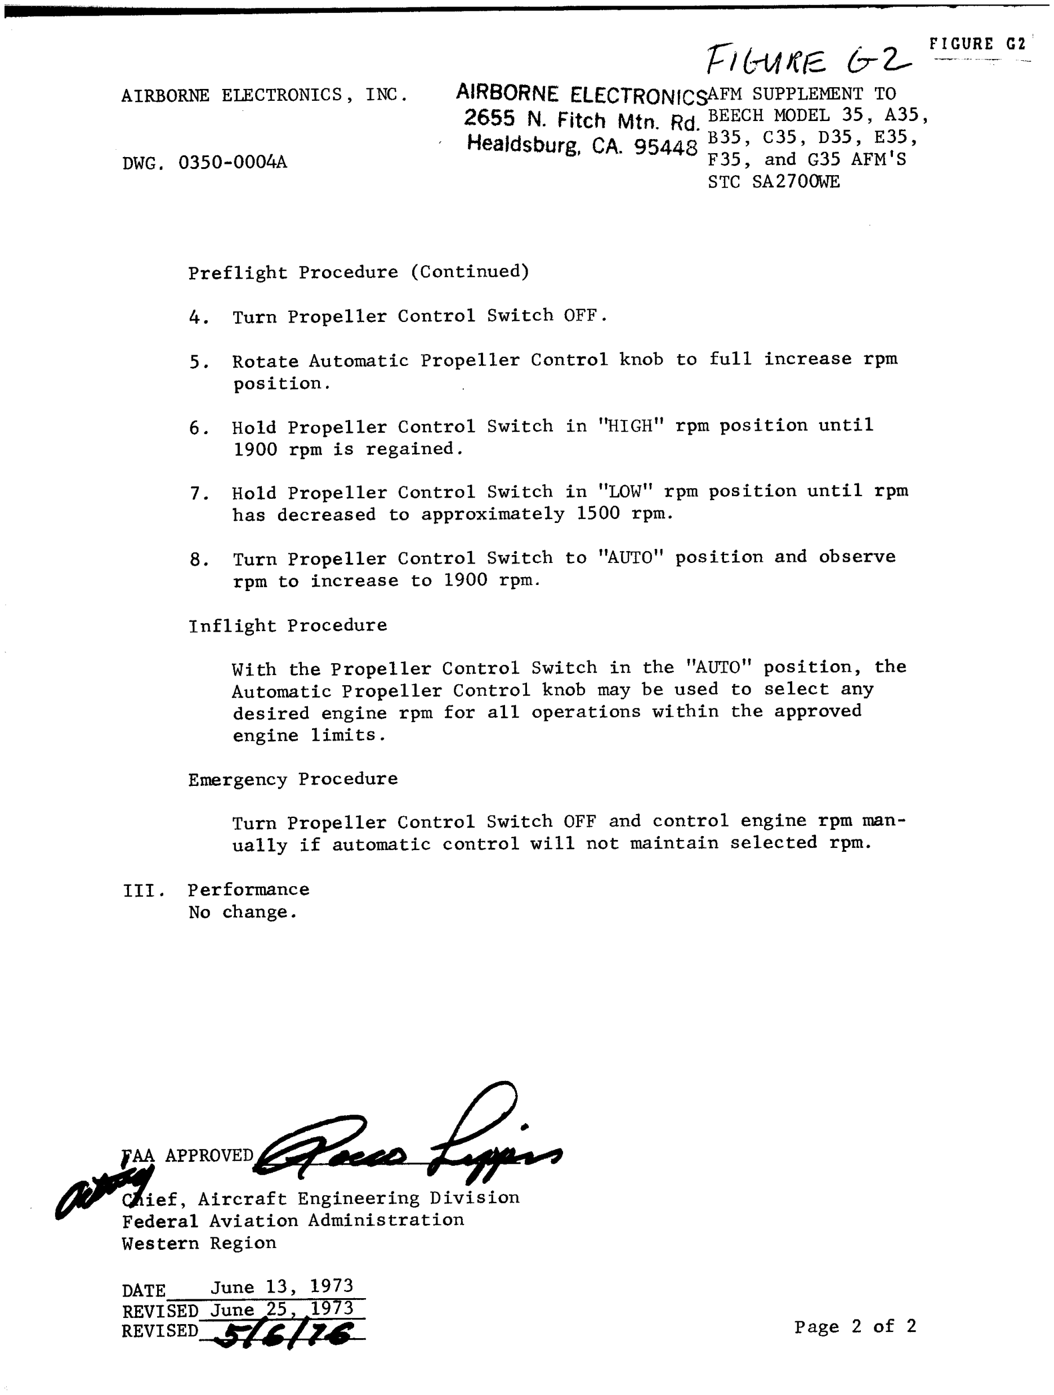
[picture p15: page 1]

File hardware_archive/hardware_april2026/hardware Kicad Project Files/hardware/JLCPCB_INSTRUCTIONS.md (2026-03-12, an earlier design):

# Generating Gerbers for Fabrication

The `.kicad_pcb` file contains correct component placement with full netlist.
You must route the board in KiCad before generating Gerbers.

## Steps
1. Open `350A_governor.kicad_pcb` in KiCad 7+
2. Follow `ROUTING_GUIDE.md` to route all connections (~45 min)
3. Edit → Fill All Zones
4. Inspect → Design Rules Checker (target: 0 errors)
5. File → Fabrication Outputs → Gerbers
   - Output directory: `gerbers/`
   - Layers: F.Cu, B.Cu, F.Mask, B.Mask, F.Silkscreen, Edge.Cuts
   - Also: File → Fabrication Outputs → Drill Files
6. Zip the `gerbers/` folder and upload to JLCPCB

## JLCPCB Settings
- Layers: 2
- Dimensions: 100×80 mm
- PCB thickness: 1.6 mm
- Surface finish: HASL (lead-free)
- Copper weight: 1 oz
- All other settings: default

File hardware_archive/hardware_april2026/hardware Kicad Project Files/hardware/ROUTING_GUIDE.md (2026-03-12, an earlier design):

# 350A Governor PCB — Routing Guide
## Open the board in KiCad 7+ and route these connections

Board: 100×80 mm, 2-layer (F.Cu signal + B.Cu GND pour)

### Before Routing
1. Open `350A_governor.kicad_pcb` in KiCad PCB Editor
2. **File → Board Setup → Constraints**: set Copper clearance 0.2mm, Track min 0.25mm
3. **Edit → Fill All Zones** (creates B.Cu GND pour)
4. Press **N** to show ratsnest (all unrouted connections)

---

### Design Rule Summary
| Net type | Width | Layer |
|---|---|---|
| Power (12V_RAW, VCC5) | 0.8 mm | B.Cu preferred |
| Relay outputs (INC/DEC) | 0.5 mm | B.Cu preferred |
| Signal | 0.25 mm | F.Cu preferred |
| GND stitching vias | 0.8mm drill, 1.6mm ann | F.Cu–B.Cu |

---

### Route in This Order

#### 1. Power rails (B.Cu — back copper, unobstructed)

**12V_RAW** (0.8mm track):
- J1 pin1 (5, 43) → B.Cu horizontal at y=4 → PS1 pin1 (88, 8) via at (88, 4)
- Also tap at (12, 4) → via → C2 pin1 (12, 28) using F.Cu stub

**VCC5** (0.6mm track):
- PS1 pin3 (88, 13.08) → F.Cu stub up → via at (88, 6) → B.Cu at y=6 left to x=14
- Tap off B.Cu y=6 bus with vias at:
  - (22, 6) → F.Cu up to R2 pin1 (24, 10) [4.7k pull-up]
  - (52, 6) → F.Cu up to C4 pin1 (52, 22), and down to Nano pad27 (50.24, 35.62) and pad30 (50.24, 28)
  - (80, 6) → F.Cu to C3 pin1 (80, 10)
  - (12, 6) via → F.Cu right to U1 pin5 (19.62, 19.62) and pin8 (19.62, 12)

**GND**: Handled by B.Cu pour. Add F.Cu–B.Cu stitching vias at:
- (12, 35), (28, 68), (60, 68), (76, 68), (92, 68)

---

#### 2. MAG signal path (F.Cu, 0.25mm)

- J1 pin7 (5, 58.24) → F.Cu right → R1 pin1 (10, 58.24)
- R1 pin2 (17.62, 58.24) → B.Cu via at (17.62, 58.24) → B.Cu at x=17.62 going UP to y=14.54 → via at (17.62, 14.54) → F.Cu right to U1 pin2 (12, 14.54)
  - *(x=17.62 is safely right of U1 right col at x=19.62; no — wait: U1 right col is at x=12+7.62=19.62, left col at x=12)*
  - *Route at x=11 instead: (17.62,58.24)→(11,58.24)→(11,14.54)→(12,14.54) all on B.Cu*
- C1 pin1 (12, 22) already on MAG_FILT — short F.Cu stub to U1 pin2 region

---

#### 3. RPM pulse: U1 output → Nano D2

- U1 pin6 (19.62, 17.08) → F.Cu right → R2 pin2 (31.62, 10)
  - Route: (19.62, 17.08) → (19.62, 10) → (31.62, 10)
- R2 pin2 (31.62, 10) → B.Cu via at (31.62, 10) → B.Cu down at x=31.62 to y=38.16 → via at (31.62, 38.16) → F.Cu right to Nano pad5 (35, 38.16)
  - *(x=31.62 is 3.38mm left of Nano left col at x=35 — safe)*

---

#### 4. INC/DEC relay signals: Nano → ULN2003A

Nano pad9 (D6_INC) at (35, 48.32):
- F.Cu right → via at (58, 48.32) → B.Cu right to U2 pin1 (78, 46)
  - Route: (35,48.32)→(58,48.32) F.Cu, via, (58,48.32)→(78,46) B.Cu *(slight angle or L-route)*

Nano pad10 (D7_DEC) at (35, 50.86):
- F.Cu right → via at (58, 50.86) → B.Cu right to U2 pin2 (78, 48.54)

ULN2003A outputs → J1 relay pins:
- U2 pin15 (INC_RELAY) at (85.62, 48.54) → B.Cu at y=48.54 left to (5, 48.08) → via → J1 pin3
- U2 pin14 (DEC_RELAY) at (85.62, 51.08) → B.Cu at y=51.08 left to (5, 50.62) → via → J1 pin4
  - *(route relay lines on B.Cu near y=48–51, below components)*

12V_COM to ULN2003A:
- U2 pin16 (85.62, 46) and pin9 (85.62, 63.78): connect via F.Cu stub at x=85.62
- Tap 12V_RAW bus: via at (85.62, 4) → F.Cu down to (85.62, 46) *(or stub right from 12V bus)*

---

#### 5. LED signals: Nano → R3/R4 → D1/D2

Nano pad11 (D8_INC_LED) at (35, 53.4) → F.Cu straight right to R3 pin1 (58, 53.4)
Nano pad12 (D9_DEC_LED) at (35, 55.94) → F.Cu straight right to R4 pin1 (58, 55.94)
R3 pin2 (65.62, 53.4) → F.Cu right to D1 pin2/anode (70, 53.4)  *(LEDs rotated 180°)*
R4 pin2 (65.62, 55.94) → F.Cu right to D2 pin2/anode (70, 55.94)
D1 pin1/GND (72.54, 53.4) and D2 pin1/GND (72.54, 55.94): short F.Cu stubs to GND pour via

---

#### 6. I²C: Nano SDA/SCL → J2

Nano pad23 (SDA) at (50.24, 45.78):
- F.Cu right → (56, 45.78) → B.Cu at y=45.78 right to (92, 51.08) → via → J2 pin3 (92, 51.08)

Nano pad24 (SCL) at (50.24, 43.24):
- F.Cu right → (56, 43.24) → B.Cu at y=43.24 right → via at (92, 53.62) → J2 pin4
  - *(Use F.Cu stubs at J2 end if B.Cu pour conflicts)*

---

#### 7. Switch signals: Nano D3-D5, D10-D11 → J2

All go F.Cu RIGHT from Nano left col → via → B.Cu → right to J2.
Use unique Y-coordinates for B.Cu runs (no crossing):

| Nano pad | Net | Nano pos | B.Cu y | J2 pin |
|---|---|---|---|---|
| pad6 | D3_SW1 | (35, 40.7) | y=40.7 | 5 (92, 56.16) |
| pad7 | D4_SW2 | (35, 43.24) | y=43.24 | 6 (92, 58.7) |
| pad8 | D5_SW3 | (35, 45.78) | y=45.78 | 7 (92, 61.24) |
| pad13 | D10_SW4 | (35, 58.48) | y=58.48 | 8 (92, 63.78) |
| pad14 | D11_SW5 | (35, 61.02) | y=61.02 | 9 (92, 66.32) |

Route each as: F.Cu from Nano pad right to x=56 → via → B.Cu horizontal at same y → via at (92, J2_pin_y) → short F.Cu stub to J2 pin.
*(All 5 B.Cu tracks run parallel at different y values, y=40.7 to y=61.02 — no crossings)*

---

#### 8. J2 power/GND

J2 pin1 (VCC5) at (92, 46): short F.Cu stub right from VCC5 bus via at (92, 6) → F.Cu stub down
J2 pin2, pin10 (GND): connect to GND pour via F.Cu stubs + stitching via

---

### Final Steps
1. **Edit → Fill All Zones**
2. **Inspect → Board Statistics** — check ratsnest shows 0 unrouted
3. **Inspect → Design Rules Checker** — should show 0 errors
4. **File → Fabrication Outputs → Gerbers** — output to `gerbers/` subfolder
5. Upload `gerbers/` folder to JLCPCB or PCBWay as zip

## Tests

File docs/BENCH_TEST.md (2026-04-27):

# Bench Test Procedure

## Why Bench Test?

You want to find every firmware bug, wiring error, and marginal solder joint **before** the board is in the engine compartment at 8,500 feet. The bench test takes about 2 hours and will catch the majority of problems.

---

## What You Need

- Assembled governor PCB (firmware flashed, all components installed)
- A second Arduino Nano (the pulse generator — ~$5)
- 12V DC bench power supply, 2A minimum
- Your spare Beech 215-210 prop control motor
- A multimeter
- An oscilloscope (recommended, not mandatory)
- Short jumper wires
- USB cable for Nano

---

## Part 1: Build the Pulse Generator

This second Nano replaces the magneto for bench testing. It outputs a square wave at a frequency that corresponds to a specific RPM, letting you dial in different simulated engine speeds.

### Flash the Pulse Generator

Create a new Arduino sketch and flash it to the SECOND (test) Nano:

```cpp
// Prop Governor Bench Test — Magneto Pulse Generator
// Simulates magneto P-lead signal for ground testing
//
// Wiring: Pin 9 → 1kΩ → Governor PCB J1 pin H (magneto input)
//         GND → Governor PCB J1 pin B (common ground)
//
// Serial commands (9600 baud):
//   1 = 1800 RPM (idle, ~90 Hz)
//   2 = 2200 RPM (economy, ~110 Hz)
//   3 = 2300 RPM (cruise, ~115 Hz)
//   4 = 2450 RPM (cruise climb, ~122 Hz)
//   5 = 2650 RPM (max, ~133 Hz)
//   +/- = adjust RPM by ±50

const int OUT_PIN = 9;
const int PULSES_PER_REV = 3;   // Match firmware setting

int targetRPM = 2300;

void setup() {
  Serial.begin(9600);
  pinMode(OUT_PIN, OUTPUT);
  Serial.println("Pulse Generator Ready");
  Serial.print("Output: "); Serial.print(rpmToHz(targetRPM)); Serial.println(" Hz");
}

void loop() {
  if (Serial.available()) {
    char c = Serial.read();
    if (c == '1') targetRPM = 1800;
    else if (c == '2') targetRPM = 2200;
    else if (c == '3') targetRPM = 2300;
    else if (c == '4') targetRPM = 2450;
    else if (c == '5') targetRPM = 2650;
    else if (c == '+') targetRPM = min(targetRPM + 50, 3000);
    else if (c == '-') targetRPM = max(targetRPM - 50, 600);
    Serial.print("RPM: "); Serial.print(targetRPM);
    Serial.print(" ("); Serial.print(rpmToHz(targetRPM)); Serial.println(" Hz)");
  }

  // Generate square wave at target frequency
  float hz = rpmToHz(targetRPM);
  long halfPeriodUs = (long)(500000.0 / hz);
  digitalWrite(OUT_PIN, HIGH);
  delayMicroseconds(halfPeriodUs);
  digitalWrite(OUT_PIN, LOW);
  delayMicroseconds(halfPeriodUs);
}

float rpmToHz(int rpm) {
  return (rpm * PULSES_PER_REV) / 60.0;
}
```

---

## Part 2: Bench Harness Wiring

```
BENCH SUPPLY (12–14V, 2A)
  +12V ─────────────────────────── J1 Pin A (12V_RAW)
  GND ──────────────────────────── J1 Pin B (GND)

PULSE GENERATOR NANO
  Pin 9 ──── 1kΩ resistor ──────── J1 Pin H (MAG input)
  GND ──────────────────────────── J1 Pin B (GND) [common with supply GND]

PROP MOTOR (wired like airframe relays)
  +12V ───── INC Relay COM ──────── Motor terminal J (via INC relay)
  +12V ───── DEC Relay COM ──────── Motor terminal J (via DEC relay)
  INC Relay NO ─────────────────── Motor terminal K (fine pitch)
  DEC Relay NO ─────────────────── Motor terminal K (coarse pitch)
  ⚠ Or connect J1 pins C and D to 12V indicator LEDs if you don't have
    external relays for the bench — this confirms governor outputs without
    running the motor. Motor test comes after relay test is confirmed.

SCOPE (if available)
  CH1 ──── J1 Pin H (view input pulse signal)
  CH2 ──── 6N137 output pin (view cleaned signal after optocoupler)
  GND ──── J1 Pin B
```

**Note on motor wiring for bench test:** The airframe relays that normally switch the motor aren't on this PCB — they live in the airframe. For bench testing, wire two small 12V SPDT relays externally. Connect relay coils to J1 pins C (INC) and D (DEC) with GND return. The relay contacts switch 12V to the motor in the correct direction for INC and DEC commands. The motor limit switches aren't needed for bench test unless you want to verify that behavior too.

---

## Part 3: Bench Test Sequence

### Test 1: Power-On State

1. Connect bench supply, do NOT engage AUTO yet
2. OLED should display:
   ```
   MANUAL
   SET: 2300 RPM
   ACT: ---- RPM
   NO MAG SIGNAL
   ```
3. Current draw: 100–200mA at 12V (normal)
4. No relay clicks should occur

### Test 2: Magneto Signal Acquisition

1. Power on pulse generator Nano — set to 2300 RPM (command `3`)
2. Governor OLED should now show actual RPM reading near 2300
3. If it shows `----` or `NO MAG SIGNAL`: check J1 pin H wiring, check 1kΩ resistor
4. If RPM reads wildly wrong: verify `PULSES_PER_REV` matches in both sketches

**Using a scope:** CH1 on J1 pin H should show the raw square wave (may have some ringing). CH2 on the 6N137 output should show a clean, sharp square wave at the same frequency. If CH2 is noisy or has missed pulses, check C1 (100nF bypass) and the 4.7kΩ pull-up (R2).

### Test 3: AUTO Mode Engagement

1. Pulse generator running at 2300 RPM
2. Press the CRUISE preset button (or verify default)
3. Engage AUTO via the panel switch
4. OLED should show:
   ```
   CRUISE        AUTO
   SET: 2300 RPM
   ACT: 2300 RPM
   HOLD ─────────
   ```
5. No relay activity — RPM matches setpoint, governor in deadband

### Test 4: RPM Error Response

1. While in AUTO mode, command pulse generator to 2200 RPM (command `2`)
2. Expected:
   - OLED shows `INC▲` status (RPM too low, commanding increase)
   - INC relay clicks on (indicator LED lights if using LEDs)
   - If motor connected: prop moves toward fine pitch
3. Command pulse generator back to 2300 RPM
4. Motor stops, OLED shows `HOLD`

5. Command pulse generator to 2400 RPM (use `+` to step up)
6. Expected:
   - OLED shows `DEC▼` (RPM too high, commanding decrease)
   - DEC relay clicks on
7. Command back to 2300 — HOLD state returns

### Test 5: Proportional Control Verification

This test verifies the proportional zone is working (motor slows near setpoint).

1. Command pulse generator to 2300 RPM (at setpoint)
2. Quickly command to 1800 RPM (large error)
3. Governor should drive INC at full duty immediately
4. Slowly step RPM back up: 2000, 2100, 2200, 2250, 2275, 2295
5. As RPM approaches within 75 RPM of setpoint, the relay should start clicking ON and OFF in a pulse pattern (proportional mode)
6. Within the 25 RPM deadband, relay activity should stop completely

If you have a scope, put it on J1 pin C (INC relay drive). You should see:
- Steady HIGH during large error (full duty)
- Pulsing HIGH/LOW as you enter the proportional zone
- Steady LOW in the deadband

### Test 6: Rotary Switch Positions

In AUTO mode at 2300 RPM (simulated), switch on position 3 (CRUISE):

1. **Turn switch to position 1 (MAX, 2650):**
   - SET display begins ramping upward from 2300 toward 2650 at 100 RPM/sec
   - A small `>` indicator appears on the SET line while ramping
   - INC relay activates as the ramped setpoint rises above the simulated 2300 RPM
   - After ~3.5 seconds, SET display reads 2650 and INC relay is at full duty
   - Advance simulated RPM to 2650 — relay should stop, HOLD state

2. **Turn switch to position 4 (ECO, 2200):**
   - SET display ramps *downward* from 2650 toward 2200
   - DEC relay activates immediately as setpoint drops below actual
   - Smooth, proportional — not a sudden lurch

3. **Turn switch to position 3 (CRUISE, 2300):**
   - Setpoint ramps back up to 2300
   - Confirm HOLD state when simulated RPM matches

4. **Between-position test:**
   - Slowly rotate switch between positions 2 and 3
   - Brief period where neither is selected: OLED should hold last preset, no relay change
   - Switch settles on new position: ramp begins smoothly

5. **Ramp rate verification (optional):**
   - From ECO (2200) to MAX (2650) = 450 RPM change
   - At 100 RPM/sec, transition should take ~4.5 seconds
   - Time it with a stopwatch — should be 4–5 seconds

### Test 7: Emergency / Low RPM Preset

1. In AUTO mode, press LOW (Emergency) button
2. Governor should command full DEC (coarse pitch direction) continuously
3. The motor should run toward full coarse pitch limit
4. When the full coarse limit switch opens (if wired) or after MAX_RELAY_MS timeout, relay should stop
5. OLED should show `LOW / COARSE`

### Test 8: Safety — Magneto Signal Loss

1. In AUTO mode, stable RPM
2. Unplug the pulse generator (simulates magneto failure or broken P-lead)
3. Within 2 seconds, governor should:
   - De-energize both relays
   - Display `ALARM: NO MAG SIGNAL`
   - Revert to MANUAL mode indication
4. Reconnect pulse generator — alarm should clear only after cycling the AUTO switch

### Test 9: Watchdog Test (Optional)

This requires a modified firmware with a deliberate infinite loop triggered by a serial command. The watchdog should reset the MCU within 250ms and return to power-on MANUAL state. Skip this test if you don't want to modify firmware — the watchdog is a hardware feature of the ATmega328P that doesn't require verification.

### Test 10: Motor Physical Test

If you have external relays wired to the motor:

1. Command RPM well below setpoint (1800 RPM target, 2300 setpoint)
2. Motor should run in the INC direction (fine pitch / more RPM)
3. Time the motor running — with correct gears, full sweep should take **16–32 seconds**
4. **If sweep takes 6–12 seconds**: WRONG GEARS. Do not fly. See original 350A Service Note 3.
5. Manually activate DEC relay — motor should reverse cleanly
6. Verify motor stops when you remove the RPM error (bring simulated RPM to setpoint)

---

## Part 4: Scope Reference Waveforms

If you have an oscilloscope, these are the waveforms to expect at key test points:

| Test point | Normal waveform |
|---|---|
| J1 pin H (magneto input) | Square wave, 90–133 Hz at normal RPM, may have ringing on edges |
| 6N137 output (pin 6) | Clean square wave, same frequency, sharp edges, 5V amplitude |
| J1 pin C or D (relay drive) | 0V in deadband; 12V steady for large errors; pulsed 12V in proportional zone |
| Nano VIN pin | 5.0V ±0.1V, minimal ripple |
| 12V supply | Should not sag more than 0.5V when relay energizes |

---

## Common Bench Test Problems

**OLED doesn't light up:**
- Check I2C address (0x3C vs 0x3D) — modify `OLED_I2C_ADDR` in firmware and reflash
- Check J2 connector wiring (SDA/SCL to Nano A4/A5)
- Verify 5V is reaching the OLED VCC pin

**RPM reads zero or wildly fluctuating:**
- Verify 1kΩ series resistor is in line between pulse generator and J1 pin H
- Check optocoupler is seated correctly in socket, pin 1 aligned
- Measure voltage at U1 pin 5 (Vcc) — should be 5V
- Verify R2 (4.7kΩ pull-up) is installed

**Relays won't energize:**
- Check J1 pins C and D for 12V output when RPM error is present (multimeter)
- If 12V present but relay doesn't click: relay coil circuit issue, not the board's problem
- Check transistors Q1–Q4: verify flat-body orientation matches silkscreen, inspect solder joints on all three leads of each device

**Motor runs in wrong direction:**
- INC and DEC relay outputs are swapped
- In the aircraft: this appears as prop going to coarse when it should go fine, or vice versa
- Fix: swap J1 pins C and D connections, or swap the motor lead polarity

**Governor keeps oscillating on the bench (expected):**
- Per the original 350A manual: *"servo dynamics are designed for best performance in flight, not on the ground."*
- Ground testing at low RPM with no aerodynamic load on the prop will show more oscillation than flight
- Do your tuning in flight, not on the bench

---

*After passing all bench tests, proceed to aircraft installation per [ASSEMBLY.md](ASSEMBLY.md) Section 8.*

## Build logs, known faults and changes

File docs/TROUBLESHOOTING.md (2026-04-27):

# Troubleshooting Guide

## Fault Codes and Display Messages

| Display Message | Meaning | Action |
|---|---|---|
| `NO MAG SIGNAL` | No magneto pulses for >2 seconds | Check Pin H wiring; check right magneto P-lead; try switching to left magneto |
| `RELAY TIMEOUT` | INC or DEC relay held on >8 seconds without RPM change | Prop may be at pitch limit; check limit switches; motor may be stalled |
| `EEPROM DEFAULT` | EEPROM unformatted or corrupt | First-boot normal; presets reset to defaults |
| `LOW VOLTAGE` | Supply voltage below 10V | Check prop circuit breaker; check wiring to Pin A |
| `MAG JITTER` | RPM reading unstable despite stable throttle | Magneto needs service; try switching to left magneto (Pin H) |

---

## Symptom-Based Troubleshooting

### Problem: OLED is blank at power-on

1. Verify 5V is present at LM2596 output — check with multimeter at PS1 pins 3 and 4
2. Check LM2596 is plugged into PS1 header correctly (not reversed)
3. Verify OLED module is connected: SDA → Nano A4, SCL → Nano A5, VCC → 5V, GND → GND
4. Try alternate I2C address: change `#define OLED_I2C_ADDR 0x3C` to `0x3D` in firmware and reflash
5. Connect Nano via USB to a computer and open Serial Monitor — should show boot messages at 9600 baud

### Problem: ACT RPM shows `----` or zero

1. Verify magneto signal is connected at J1 Pin H
2. Check R1 (10kΩ) is installed between Pin H and U1 pin 2 (MAG_ANODE)
3. Check U1 (6N137) is seated correctly in socket — pin 1 notch toward board edge
4. Check R2 (4.7kΩ pull-up) installed between 5V and U1 output
5. With engine running: put scope or multimeter on U1 pin 6 — should see pulses at ~90–133 Hz range
6. Try left magneto: disconnect Pin H from right magneto P-lead, temporarily connect to left magneto P-lead (requires re-routing or a switch)

### Problem: RPM display reads wrong value (e.g., reads half of actual)

- `PULSES_PER_REV` is set incorrectly — verify engine is 6-cylinder Continental and firmware has `#define PULSES_PER_REV 3`
- If reads double: set to `PULSES_PER_REV 6` (unusual, but some magneto configurations fire twice per revolution)
- Cross-check against known panel tachometer; if tach is suspect, use the fluorescent lamp calibration method from original 350A Service Note 5

### Problem: AUTO mode does nothing (no relay activity)

1. Verify AUTO switch is in correct position and 12V present at J1 Pin A
2. Check Nano D6 and D7 with multimeter — should show 5V when error exceeds deadband
3. Check transistors Q1–Q4: verify flat-body orientation matches PCB silkscreen; inspect solder joints on all three leads of each device
4. Check J1 pins C and D with multimeter — should show 12V when governor is commanding correction
5. If C and D have 12V but motor doesn't run: airframe relay issue, not the governor

### Problem: RPM hunts / oscillates in flight

This is the problem this controller was designed to fix. If hunting persists after installation:

1. **Increase deadband first:** Change `#define DEADBAND_RPM 25` to `35`, then `50`. Reflash. Try in flight. Most hunting is cured at 35–40 RPM deadband with a fresh motor.
2. **Check for magneto noise:** If both LEDs flash erratically, the RPM signal is noisy. Switch Pin H to left magneto and compare. If better → right magneto needs service.
3. **Verify gear timing:** With engine off, time manual prop sweep. Should be 16–32 seconds. If 6–12 seconds → wrong gears in motor (see original 350A Service Note 3). Do not fly until corrected.
4. **Check brush spring:** Correct brush is Beech PN 31-408, spring wire diameter 0.027". Wrong brushes cause oscillation in both old and new governors.
5. **Increase proportional zone:** Change `#define PROP_ZONE_RPM 75` to `100` or `150` for more gradual approach to setpoint.

### Problem: Prop goes to coarse when it should go fine (wrong direction)

- INC and DEC relay outputs are swapped
- Two ways to fix:
  1. Swap J1 pins C and D in the aircraft connector
  2. Edit firmware: swap `D6_INC_RELAY` and `D7_DEC_RELAY` pin definitions and reflash

### Problem: Emergency/Low preset doesn't stop at full coarse

- Full coarse limit switch not in the relay circuit, or limit switch wiring reversed
- See original 350A Service Note 1, Section 7 (Relay and Limit Switch Test) for diagnostic
- Verify limit switch wires were reconnected correctly after last prop overhaul

### Problem: Preset buttons not responding

1. Verify button wiring to correct Nano pins (D10, D11, D12, A1)
2. Buttons should connect the Nano pin to GND — firmware uses internal pull-ups
3. Check continuity across button contacts with multimeter in beep mode
4. Verify J2 connector seating

### Problem: OLED shows correct SET but incorrect ACT RPM

- Check panel tachometer calibration — see original 350A Service Note 5 (fluorescent lamp test)
- Check `PULSES_PER_REV` setting
- If ACT reads consistently 10–20 RPM high or low, add a `#define RPM_OFFSET 10` calibration constant to firmware

---

## Diagnostic Jumper Tests

These are equivalent to the original 350A's airframe systems test (Service Note 1). Use safety wire formed into a "U" shape.

**Test INC relay drive:**
1. Master ON, prop switch AUTO, engine OFF
2. Connect J1 Pin A to J1 Pin C with jumper wire
3. Motor should run toward fine pitch (high RPM direction)
4. Motor should stop when full fine limit switch opens
5. Remove jumper

**Test DEC relay drive:**
1. Master ON, prop switch AUTO, engine OFF
2. Connect J1 Pin A to J1 Pin D with jumper wire
3. Motor should run toward coarse pitch (low RPM direction)
4. Motor should stop when full coarse limit switch opens
5. Remove jumper

If motor fails these tests: limit switch wiring, relay, or motor issue — not the governor.

If motor runs but doesn't stop at limit: limit switches not in circuit, or wired backwards. See aircraft wiring diagrams.

---

## Checking the Magneto Signal Quality

Poor magneto signal quality (weak impulse springs, worn rubber couplings, deteriorated P-lead filter) causes the RPM reading to jitter, which causes the governor to overcorrect.

**Quick check:** In flight, watch the `ACT:` RPM reading on the OLED. At steady cruise with stable throttle and altitude:
- **Good signal:** ACT reading holds within ±15 RPM
- **Marginal signal:** ACT reading bounces ±25–40 RPM despite stable flight
- **Bad signal:** ACT reading swings ±50+ RPM or shows erratic jumps

**Test:** Switch J1 Pin H from right magneto to left magneto and compare. If left is steadier, the right magneto needs attention.

**Firmware response to noisy signal:** The 8-sample rolling average in the RPM calculation rejects single-pulse outliers. If your magneto is very noisy, increasing the average to 16 samples (`#define RPM_AVG_SAMPLES 8` → `16`) will smooth the reading at the cost of slightly slower response to genuine RPM changes.

---

## Factory Defaults (after EEPROM reset)

If EEPROM is cleared (new Nano, or deliberate reset), firmware boots with:

| Parameter | Default |
|---|---|
| PULSES_PER_REV | 3 |
| Preset 1 (MAX) | 2650 RPM |
| Preset 2 (CLIMB) | 2450 RPM |
| Preset 3 (CRUISE) | 2300 RPM |
| Preset 4 (ECONOMY) | 2200 RPM |
| Preset 5 (LOW) | Full coarse |
| Deadband | 25 RPM |
| Proportional zone | 75 RPM |
| Default active preset | CRUISE |
| Mode at power-on | MANUAL |

---

## Getting Help

1. Check this document first
2. Review the original 350A documentation in `docs/original_350A/` — many airframe issues are covered there and still apply
3. Open a GitHub issue with:
   - Aircraft serial number range (D-XXXX)
   - Engine model
   - Firmware version (shown on OLED startup screen)
   - Description of symptom
   - What you've already tried
4. American Bonanza Society forums — experienced members may have seen the same issue

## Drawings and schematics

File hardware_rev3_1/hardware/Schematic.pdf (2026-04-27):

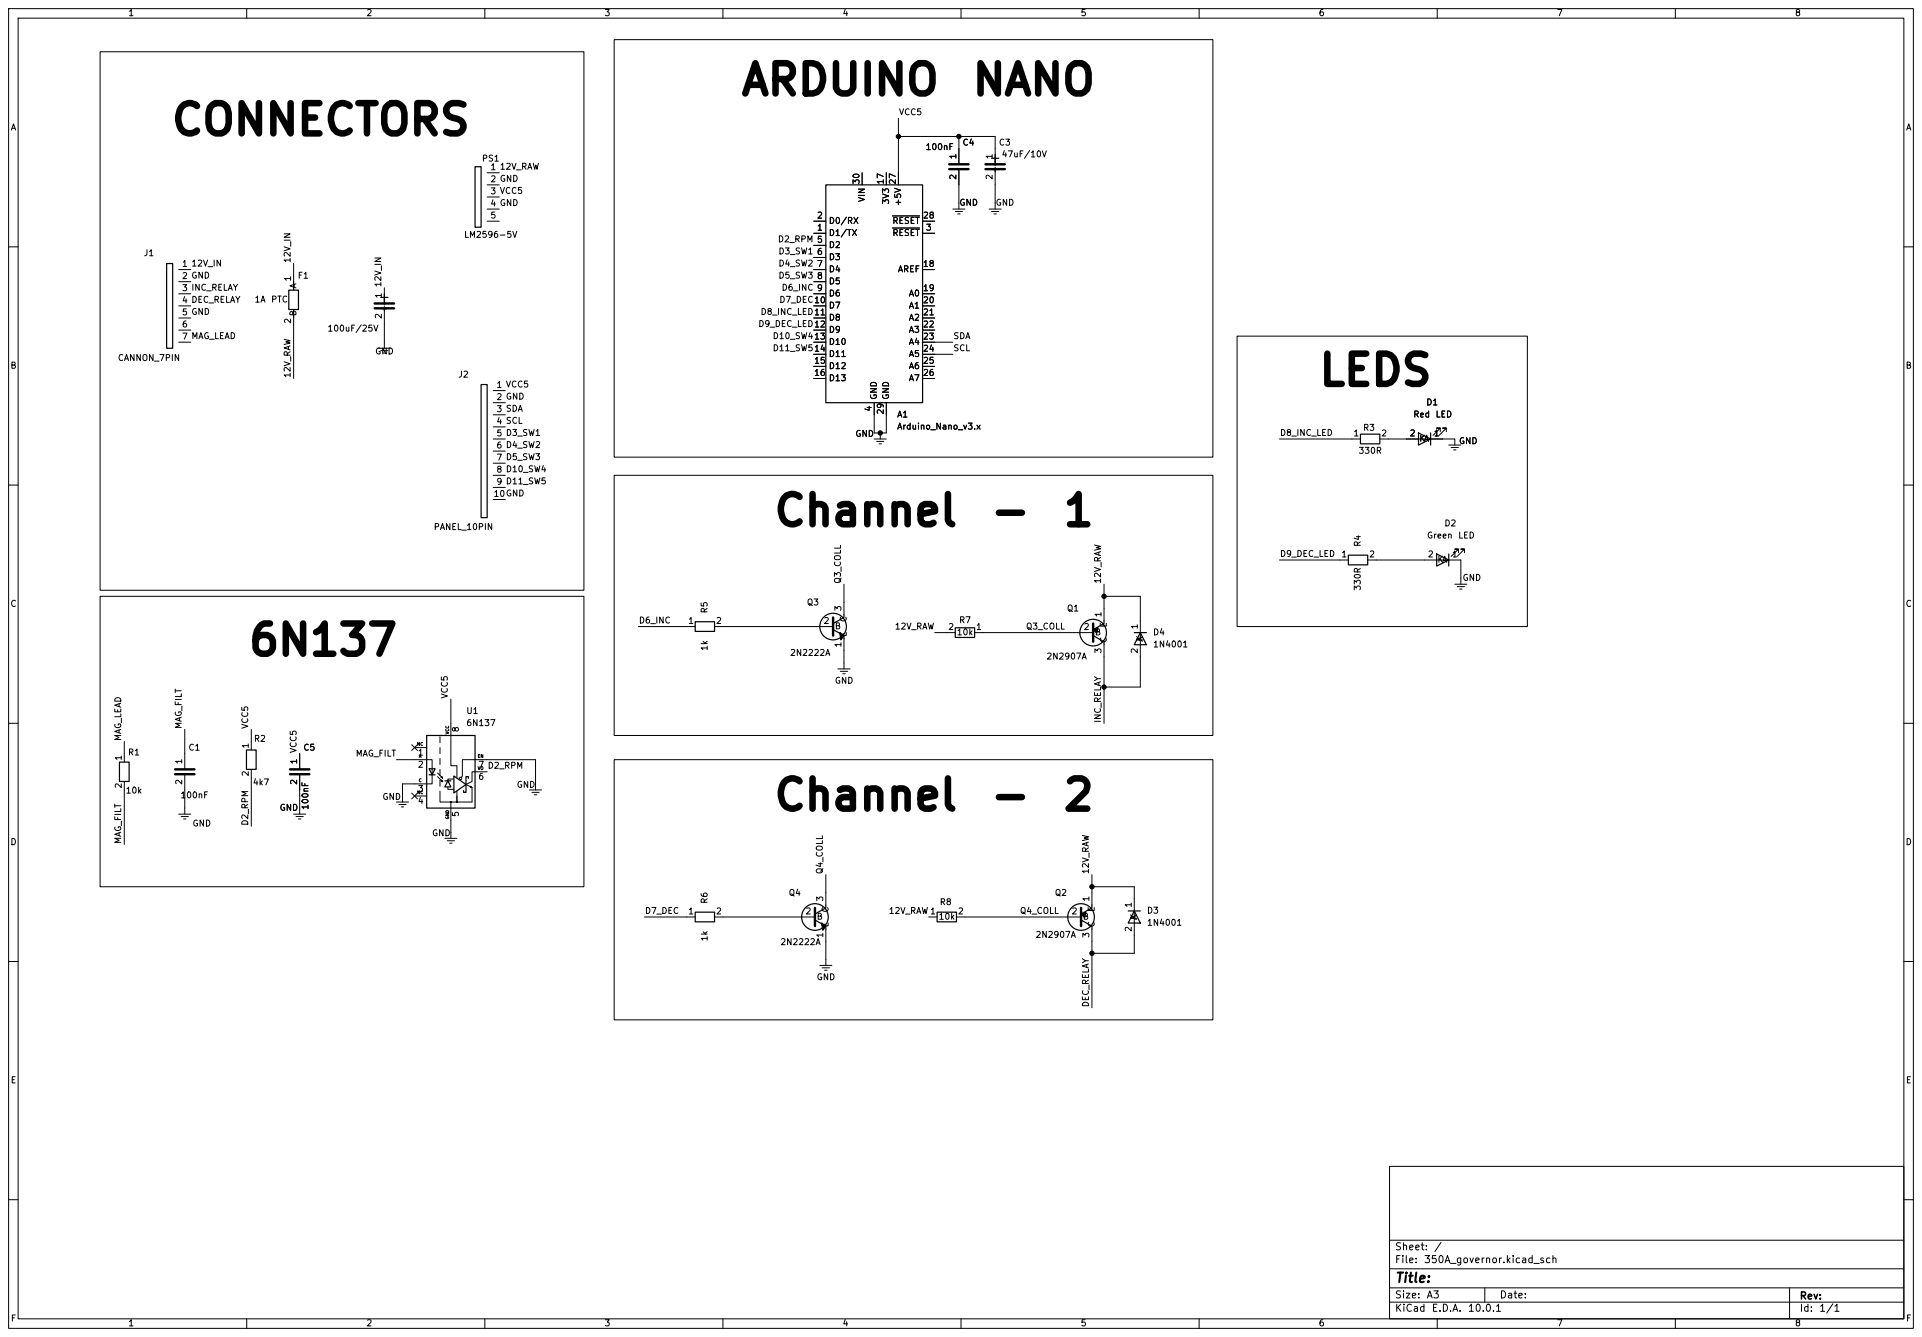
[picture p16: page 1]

Size: A3 | Rev:
KiCad E.D.A. 10.0.1 | Id: 1/1

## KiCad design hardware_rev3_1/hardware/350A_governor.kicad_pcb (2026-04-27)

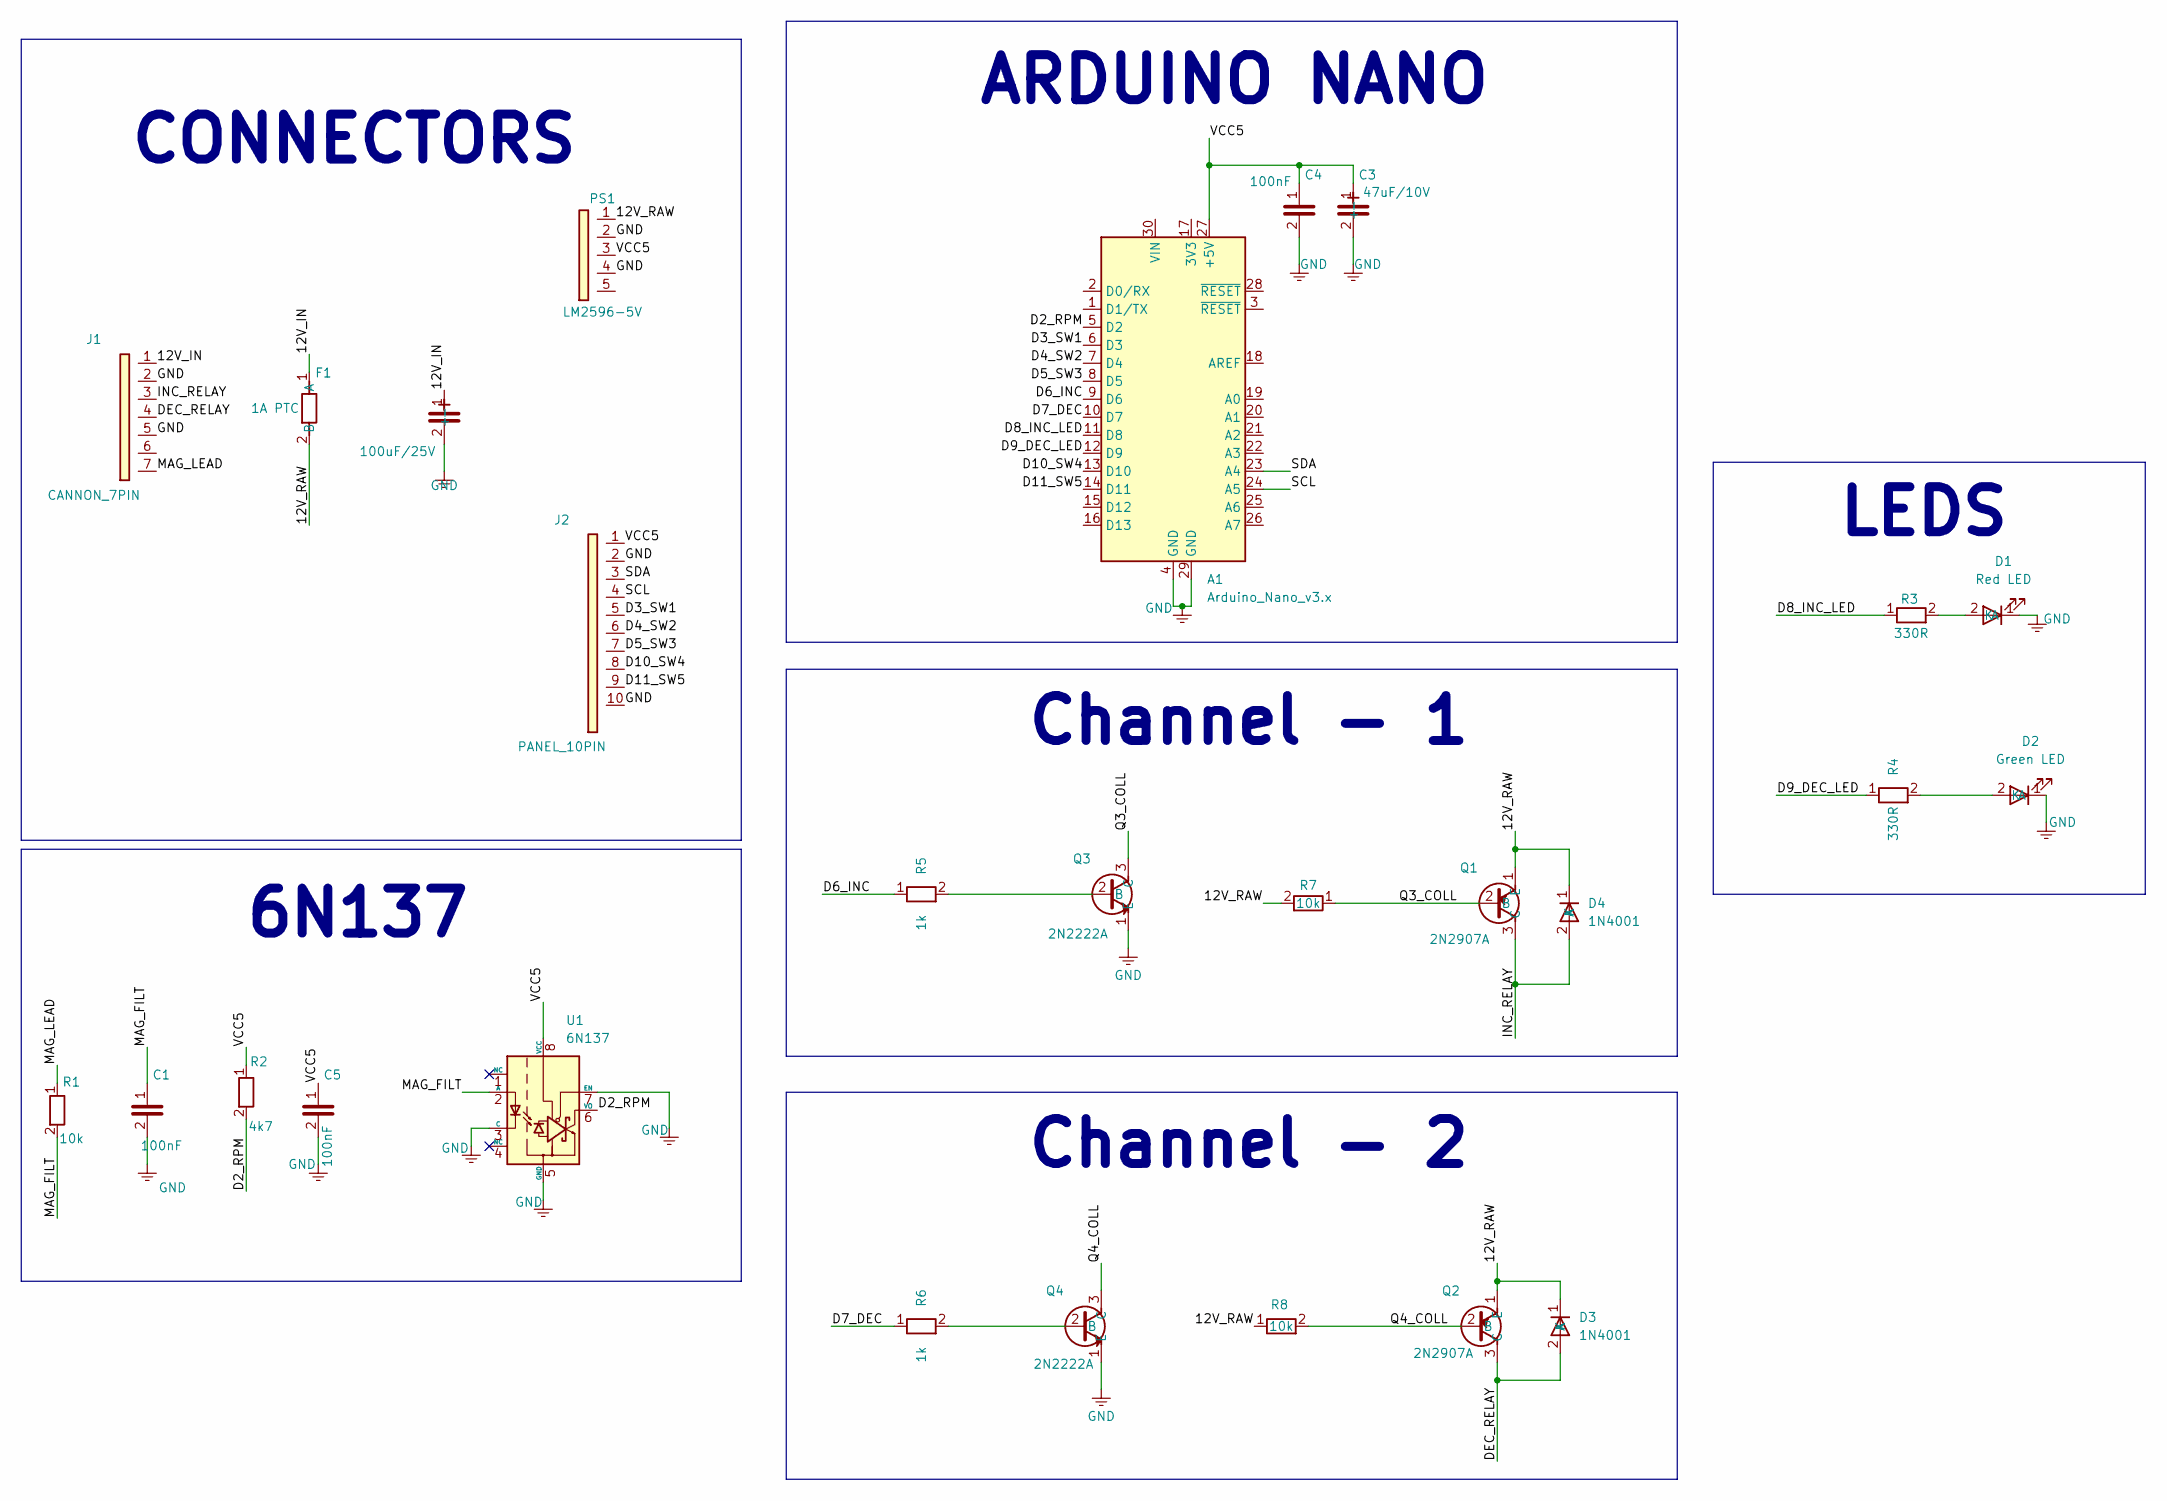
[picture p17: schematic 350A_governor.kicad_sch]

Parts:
A1: Arduino_Nano_v3.x; Arduino_Nano
C1, C4, C5: 100nF; C_Disc_D3.8mm_W2.6mm_P2.50mm
C2: 100uF/25V; CP_Radial_D5.0mm_P2.50mm
C3: 47uF/10V; CP_Radial_D8.0mm_P3.80mm
D1: Red LED
D2: Green LED
D3, D4: 1N4001; D_DO-41_SOD81_P10.16mm_Horizontal
F1: 1A PTC; Fuse_BelFuse_0ZRE0012FF_L8.3mm_W3.8mm
J1: CANNON_7PIN; PinHeader_1x07_P2.54mm_Vertical
J2: PANEL_10PIN; PinHeader_1x10_P2.54mm_Vertical
PS1: LM2596-5V; PinHeader_1x05_P2.54mm_Vertical
Q1, Q2: 2N2907A; TO-92L_Inline
Q3, Q4: 2N2222A; TO92254P470H750-3
R1, R7, R8: 10k; R_Axial_DIN0207_L6.3mm_D2.5mm_P7.62mm_Horizontal
R2: 4k7; R_Axial_DIN0207_L6.3mm_D2.5mm_P7.62mm_Horizontal
R3, R4: 330R; R_Axial_DIN0207_L6.3mm_D2.5mm_P7.62mm_Horizontal
R5, R6: 1k; R_Axial_DIN0207_L6.3mm_D2.5mm_P7.62mm_Horizontal
U1: 6N137; DIP-8_W7.62mm

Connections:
/12V_IN: C2.1 (+), F1.1 (A), J1.1
/12V_RAW: D3.1 (K), D4.1 (K), F1.2 (B), PS1.1, Q1.1 (E), Q2.1 (E), R7.2, R8.1
/D2_RPM: A1.5 (D2), R2.2, U1.6 (VO)
/D3_SW1: A1.6 (D3), J2.5
/D4_SW2: A1.7 (D4), J2.6
/D5_SW3: A1.8 (D5), J2.7
/D6_INC: A1.9 (D6), R5.1
/D7_DEC: A1.10 (D7), R6.1
/D8_INC_LED: A1.11 (D8), R3.1
/D9_DEC_LED: A1.12 (D9), R4.1
/D10_SW4: A1.13 (D10), J2.8
/D11_SW5: A1.14 (D11), J2.9
/DEC_RELAY: D3.2 (A), J1.4, Q2.3 (C)
/INC_RELAY: D4.2 (A), J1.3, Q1.3 (C)
/MAG_FILT: C1.1, R1.2, U1.2 (A)
/MAG_LEAD: J1.7, R1.1
/Q3_COLL: Q1.2 (B), Q3.3 (C), R7.1
/Q4_COLL: Q2.2 (B), Q4.3 (C), R8.2
/SCL: A1.24 (A5), J2.4
/SDA: A1.23 (A4), J2.3
/VCC5: A1.27 (+5V), C3.1 (+), C4.1, C5.1, J2.1, PS1.3, R2.1, U1.8 (VCC)
GND: A1.4 (GND), A1.29 (GND), C1.2, C2.2 (-), C3.2 (-), C4.2, C5.2, D1.1 (K), D2.1 (K), J1.2, J1.5, J2.2, J2.10, PS1.2, PS1.4, Q3.1 (E), Q4.1 (E), U1.3 (C), U1.5 (GND), U1.7 (EN)
unnamed: D1.2 (A), R3.2
unnamed: D2.2 (A), R4.2
unnamed: Q3.2 (B), R5.2
unnamed: Q4.2 (B), R6.2

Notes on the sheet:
ARDUINO NANO
Channel - 1
CONNECTORS
6N137
Channel - 2
LEDS

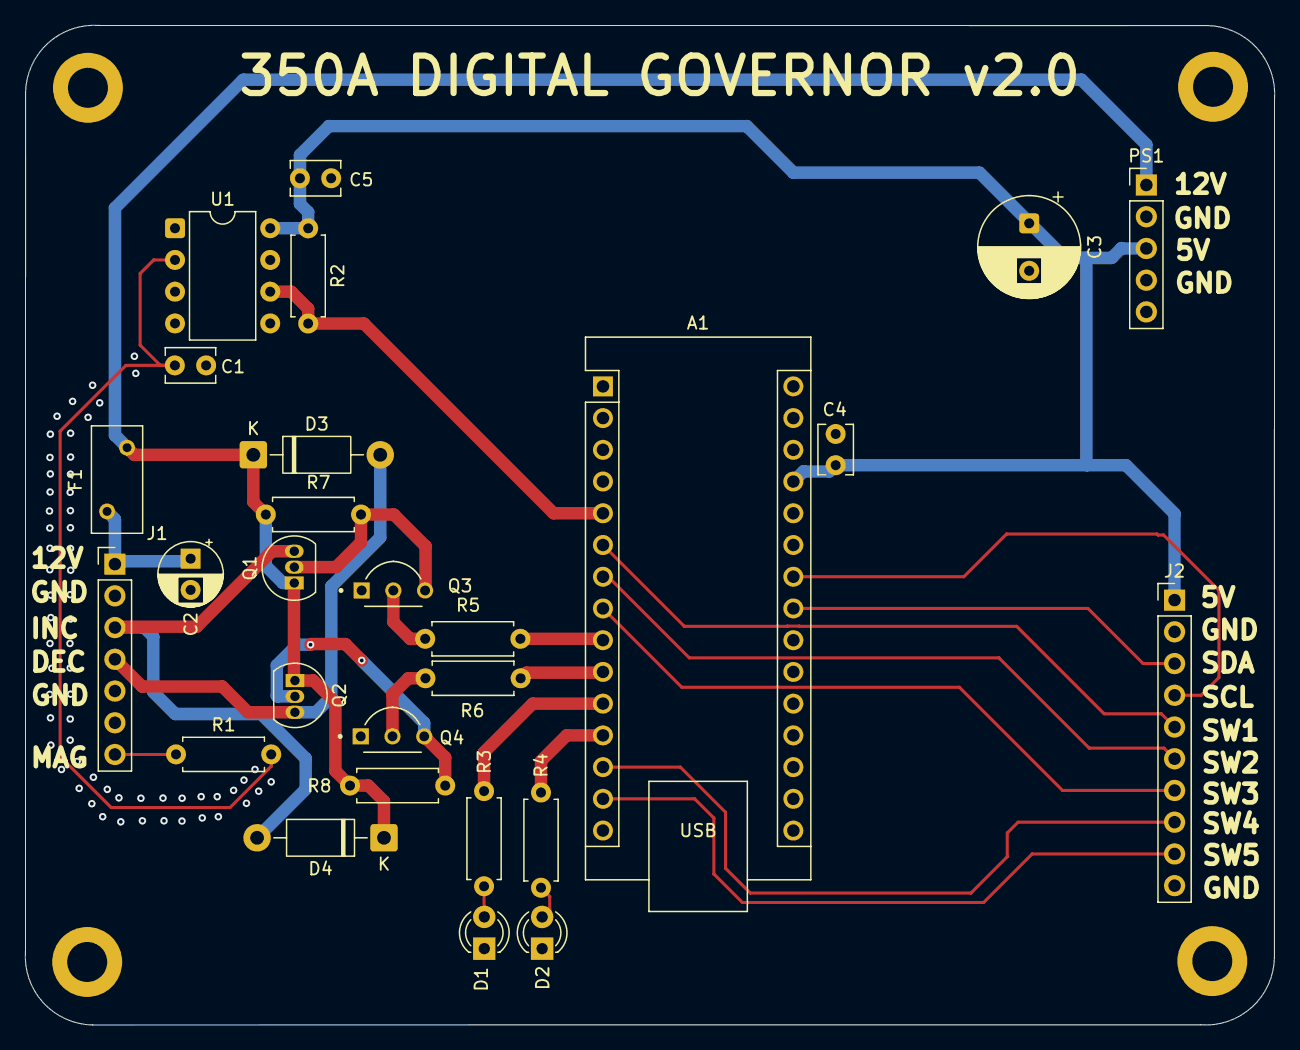
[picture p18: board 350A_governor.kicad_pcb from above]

Board: 2 copper layers, 100.0 x 80.0 mm, 27 parts (0 on the bottom side), 26 nets.

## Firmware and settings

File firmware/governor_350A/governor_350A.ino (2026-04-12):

/**
 * Beechcraft Bonanza Electric Prop — Digital Governor Controller
 * Replacement firmware for Airborne Electronics 350A (STC SA2700WE)
 *
 * Platform:  Arduino Nano (ATmega328P, 5V, 16MHz)
 * Libraries: Adafruit SSD1306, Adafruit GFX
 *
 * Panel interface: 5-position rotary switch (one position per RPM preset)
 *
 * ── CONFIGURATION ───────────────────────────────────────────────────────────
 * Set PULSES_PER_REV before flashing. All other parameters have safe defaults.
 * ─────────────────────────────────────────────────────────────────────────────
 *
 * MIT License — see repository LICENSE file
 * https://github.com/billmallard/Beech215PropController
 */

#include <Wire.h>
#include <Adafruit_GFX.h>
#include <Adafruit_SSD1306.h>
#include <EEPROM.h>
#include <avr/wdt.h>

// ── CRITICAL: SET BEFORE FLASHING ────────────────────────────────────────────
#define PULSES_PER_REV      3       // 6-cyl Continental (IO-470, IO-520, E-185/E-225)
                                    // Use 2 for 4-cylinder engines

// ── RPM PRESETS ───────────────────────────────────────────────────────────────
#define PRESET_MAX          2650    // Position 1 — takeoff / full fine pitch
#define PRESET_CRUISE_CLIMB 2450    // Position 2 — best-power climb
#define PRESET_CRUISE       2300    // Position 3 — normal cruise
#define PRESET_ECONOMY      2200    // Position 4 — long-range economy
// Position 5 = EMERGENCY/LOW — drives to full coarse, no RPM target

// ── CONTROL TUNING ────────────────────────────────────────────────────────────
#define DEADBAND_RPM        25      // No correction within +/-25 RPM of setpoint
#define PROP_ZONE_RPM       75      // Proportional slowdown begins within +/-75 RPM
#define MIN_DUTY_PCT        25      // Minimum motor duty in proportional zone (%)
#define CONTROL_INTERVAL_MS 100     // Control loop runs every 100ms

// ── SETPOINT RAMPING ──────────────────────────────────────────────────────────
// When switching presets, the setpoint walks toward the new target at this
// rate rather than jumping instantly. This prevents a sudden large RPM error
// from commanding full-duty relay drive the moment you turn the knob.
//
// 100 RPM/sec: ECO->MAX (450 RPM step) takes ~4.5 seconds
// Increase for snappier transitions; decrease for more gradual.
#define RAMP_RATE_RPM_PER_SEC  100

// ── SAFETY LIMITS ─────────────────────────────────────────────────────────────
#define MAG_TIMEOUT_MS      2000    // Alarm if no magneto pulse for 2 seconds
#define MAX_RELAY_MS        8000    // Safety: max relay on-time without RPM movement
#define RPM_AVG_SAMPLES     8       // Rolling average depth for noise rejection

// ── SWITCH DEBOUNCE ───────────────────────────────────────────────────────────
// Rotary switches are "break before make" — briefly no pin is grounded as
// the wiper moves between positions. We ignore transitions shorter than this.
#define SWITCH_SETTLE_MS    80

// ── HARDWARE PINS ─────────────────────────────────────────────────────────────
#define PIN_RPM_INPUT   2   // 6N137 output -> INT0 (hardware interrupt)
#define PIN_SW_POS1     3   // Rotary switch position 1: MAX (2650)
#define PIN_SW_POS2     4   // Rotary switch position 2: CRUISE CLIMB (2450)
#define PIN_SW_POS3     5   // Rotary switch position 3: CRUISE (2300)
#define PIN_INC_RELAY   6   // NPN base (via 1kΩ) -> PNP high-side switch -> INC RPM relay (fine pitch)
#define PIN_DEC_RELAY   7   // NPN base (via 1kΩ) -> PNP high-side switch -> DEC RPM relay (coarse pitch)
#define PIN_INC_LED     8   // Red LED — INC activity indicator
#define PIN_DEC_LED     9   // Green LED — DEC activity indicator
#define PIN_SW_POS4     10  // Rotary switch position 4: ECONOMY (2200)
#define PIN_SW_POS5     11  // Rotary switch position 5: LOW/EMERGENCY COARSE
// A4 = SDA (OLED), A5 = SCL (OLED) — claimed by Wire library

// Rotary switch wiring:
//   COMMON terminal -> GND
//   Each position terminal -> its Nano pin above
//   Internal pull-ups keep all pins HIGH; selected position pulls its pin LOW.
//   No external resistors needed.

// ── DISPLAY ───────────────────────────────────────────────────────────────────
#define OLED_I2C_ADDR   0x3C    // Change to 0x3D if display is blank at boot
#define SCREEN_WIDTH    128
#define SCREEN_HEIGHT   64

// ── EEPROM LAYOUT ─────────────────────────────────────────────────────────────
#define EE_MAGIC        0x00    // 1 byte: 0xAE = valid data present
#define EE_PRESET1      0x01    // 2 bytes uint16
#define EE_PRESET2      0x03
#define EE_PRESET3      0x05
#define EE_PRESET4      0x07
#define EEPROM_MAGIC    0xAE

// ── PRESET TABLE ──────────────────────────────────────────────────────────────
struct Preset {
  const char* name;       // Short name for OLED (fits in large font)
  const char* label;      // Descriptive label (small font, second row)
  uint16_t    rpm;        // Target RPM (unused if fullCoarse)
  bool        fullCoarse; // true: drive to coarse limit, no RPM target
};

Preset presets[5] = {
  { "MAX",    "TAKEOFF",    PRESET_MAX,          false },
  { "CLB",    "CRS CLIMB",  PRESET_CRUISE_CLIMB, false },
  { "CRUISE", "CRUISE",     PRESET_CRUISE,       false },
  { "ECO",    "ECONOMY",    PRESET_ECONOMY,      false },
  { "LOW",    "EMER COARSE",0,                   true  },
};

// ── SYSTEM STATE ──────────────────────────────────────────────────────────────
enum ControlMode { MODE_MANUAL, MODE_AUTO, MODE_ALARM };
enum RelayState  { RELAY_OFF, RELAY_INC, RELAY_DEC };

ControlMode currentMode  = MODE_MANUAL;
RelayState  relayState   = RELAY_OFF;
String      alarmMessage = "";

int8_t activePreset    = 2;  // Active switch position (0-4), default CRUISE
int8_t lastValidPreset = 2;  // Last confirmed position (held during transitions)

// ── SETPOINT RAMP STATE ───────────────────────────────────────────────────────
float    rampedSetpoint = (float)PRESET_CRUISE; // What the control loop tracks
float    targetSetpoint = (float)PRESET_CRUISE; // Where the ramp is headed
uint32_t lastRampTime   = 0;

// ── RPM MEASUREMENT ───────────────────────────────────────────────────────────
volatile uint32_t lastPulseTime_us = 0;
volatile uint32_t pulseInterval_us = 0;
volatile bool     newPulse         = false;

uint32_t rpmBuffer[RPM_AVG_SAMPLES];
uint8_t  rpmBufIdx  = 0;
bool     rpmBufFull = false;

float    actualRPM       = 0.0;
uint32_t lastMagPulse_ms = 0;

// ── RELAY TIMING ──────────────────────────────────────────────────────────────
uint32_t relayOnTime_ms    = 0;
uint32_t lastControlRun    = 0;
uint32_t lastDisplayUpdate = 0;

// ── DISPLAY ───────────────────────────────────────────────────────────────────
Adafruit_SSD1306 display(SCREEN_WIDTH, SCREEN_HEIGHT, &Wire, -1);
bool displayOK = false;


// =============================================================================
// RPM MEASUREMENT
// =============================================================================

float calculateRPM() {
  if (pulseInterval_us == 0) return 0.0;
  if ((millis() - lastMagPulse_ms) > MAG_TIMEOUT_MS) return 0.0;

  rpmBuffer[rpmBufIdx % RPM_AVG_SAMPLES] = pulseInterval_us;
  rpmBufIdx++;
  if (rpmBufIdx >= RPM_AVG_SAMPLES) rpmBufFull = true;

  uint8_t  count = rpmBufFull ? RPM_AVG_SAMPLES : rpmBufIdx;
  uint32_t total = 0;
  for (uint8_t i = 0; i < count; i++) total += rpmBuffer[i % RPM_AVG_SAMPLES];
  uint32_t avg = total / count;

  return (avg > 0) ? (60000000.0f / ((float)avg * PULSES_PER_REV)) : 0.0;
}

void updateRPM() {
  if (!newPulse) return;
  newPulse = false;
  lastMagPulse_ms = millis();
  actualRPM = calculateRPM();
}

bool magSignalLost() {
  return (millis() - lastMagPulse_ms) > MAG_TIMEOUT_MS;
}


// =============================================================================
// ROTARY SWITCH READING
// =============================================================================

const uint8_t SWITCH_PINS[5] = {
  PIN_SW_POS1, PIN_SW_POS2, PIN_SW_POS3, PIN_SW_POS4, PIN_SW_POS5
};

// Returns 0-4 if a position pin is grounded, -1 if between positions.
int8_t readSwitchRaw() {
  for (uint8_t i = 0; i < 5; i++) {
    if (digitalRead(SWITCH_PINS[i]) == LOW) return (int8_t)i;
  }
  return -1;
}

// Debounced switch read. Handles break-before-make transitions by requiring
// the new position to be stable for SWITCH_SETTLE_MS before accepting it.
// Returns a confirmed position (0-4), never -1.
static uint32_t switchChangeTime = 0;
static int8_t   pendingPosition  = -1;

int8_t readSwitch() {
  int8_t raw = readSwitchRaw();

  if (raw == -1) {
    // Between positions: hold current, reset any pending candidate
    pendingPosition = -1;
    return lastValidPreset;
  }

  if (raw == lastValidPreset) {
    // No change — already at a stable position
    pendingPosition = -1;
    return lastValidPreset;
  }

  // Position appears to have changed
  if (raw != pendingPosition) {
    // New candidate — start settle timer
    pendingPosition  = raw;
    switchChangeTime = millis();
  } else if ((millis() - switchChangeTime) >= SWITCH_SETTLE_MS) {
    // Stable for required time — accept the change
    lastValidPreset = raw;
    pendingPosition = -1;
  }

  return lastValidPreset; // Return last confirmed position while settling
}


// =============================================================================
// SETPOINT RAMPING
// =============================================================================

// Called every loop iteration. Walks rampedSetpoint toward targetSetpoint
// at RAMP_RATE_RPM_PER_SEC. The control loop always tracks rampedSetpoint,
// so preset transitions feel smooth rather than lurching to full motor duty.
//
// Exception: EMERGENCY/LOW (full coarse) bypasses ramping and engages
// immediately — that's exactly the case where you want instant response.

void updateRamp() {
  if (presets[activePreset].fullCoarse) return;

  uint32_t now     = millis();
  float    elapsed = (now - lastRampTime) / 1000.0f; // seconds
  lastRampTime = now;

  float maxStep = RAMP_RATE_RPM_PER_SEC * elapsed;
  float diff    = targetSetpoint - rampedSetpoint;

  if (fabs(diff) <= maxStep) {
    rampedSetpoint = targetSetpoint; // Close enough — snap to target
  } else {
    rampedSetpoint += (diff > 0) ? maxStep : -maxStep;
  }
}


// =============================================================================
// RELAY CONTROL
// =============================================================================

void relayOff() {
  digitalWrite(PIN_INC_RELAY, LOW);
  digitalWrite(PIN_DEC_RELAY, LOW);
  digitalWrite(PIN_INC_LED,   LOW);
  digitalWrite(PIN_DEC_LED,   LOW);
  relayState    = RELAY_OFF;
  relayOnTime_ms = 0;
}

// Time-proportioned relay drive within each 100ms control window.
// duty = 0.0 (off) to 1.0 (fully on throughout window).
// NOT audio-frequency PWM — relay contacts are rated for this.
void setRelay(RelayState direction, float duty) {
  if (direction == RELAY_OFF) { relayOff(); return; }

  // Safety: cut relay if it's been on too long without RPM change
  if (relayState == direction && relayOnTime_ms > 0) {
    if ((millis() - relayOnTime_ms) > MAX_RELAY_MS) {
      relayOff();
      setAlarm("RELAY TIMEOUT");
      return;
    }
  }

  duty = constrain(duty, 0.0f, 1.0f);
  uint32_t pos       = millis() % CONTROL_INTERVAL_MS;
  uint32_t onMs      = (uint32_t)(duty * CONTROL_INTERVAL_MS);
  bool     shouldBeOn = (pos < onMs);

  if (direction == RELAY_INC) {
    digitalWrite(PIN_INC_RELAY, shouldBeOn ? HIGH : LOW);
    digitalWrite(PIN_DEC_RELAY, LOW);
    digitalWrite(PIN_INC_LED,   shouldBeOn ? HIGH : LOW);
    digitalWrite(PIN_DEC_LED,   LOW);
  } else {
    digitalWrite(PIN_DEC_RELAY, shouldBeOn ? HIGH : LOW);
    digitalWrite(PIN_INC_RELAY, LOW);
    digitalWrite(PIN_DEC_LED,   shouldBeOn ? HIGH : LOW);
    digitalWrite(PIN_INC_LED,   LOW);
  }

  if (relayState != direction) relayOnTime_ms = millis();
  relayState = direction;
}


// =============================================================================
// ALARM HANDLING
// =============================================================================

void setAlarm(const char* msg) {
  relayOff();
  currentMode  = MODE_ALARM;
  alarmMessage = String(msg);
  Serial.print("ALARM: "); Serial.println(msg);
}

void clearAlarm() {
  if (currentMode == MODE_ALARM) {
    currentMode  = MODE_MANUAL;
    alarmMessage = "";
  }
}


// =============================================================================
// CONTROL ALGORITHM
// =============================================================================

// Runs every 100ms. Tracks rampedSetpoint so preset transitions are smooth.
void runControlLoop() {
  if (currentMode != MODE_AUTO) { relayOff(); return; }

  // Safety checks first
  if (magSignalLost()) {
    relayOff(); setAlarm("NO MAG SIGNAL"); return;
  }
  if (actualRPM > 0 && (actualRPM < 400 || actualRPM > 3500)) {
    relayOff(); setAlarm("RPM OUT OF RANGE"); return;
  }

  // Full coarse — immediate, no ramping
  if (presets[activePreset].fullCoarse) {
    setRelay(RELAY_DEC, 1.0);
    return;
  }

  // Proportional control against the ramped (smooth) setpoint
  float error = rampedSetpoint - actualRPM;

  if (fabs(error) < DEADBAND_RPM) {
    relayOff();
    return;
  }

  float duty;
  if (fabs(error) >= PROP_ZONE_RPM) {
    duty = 1.0;
  } else {
    duty = fabs(error) / PROP_ZONE_RPM;
    duty = max(duty, (float)(MIN_DUTY_PCT) / 100.0f);
  }

  setRelay((error > 0) ? RELAY_INC : RELAY_DEC, duty);
}


// =============================================================================
// DISPLAY
// =============================================================================

void updateDisplay() {
  if (!displayOK) return;
  display.clearDisplay();
  display.setTextColor(SSD1306_WHITE);

  if (currentMode == MODE_ALARM) {
    display.setTextSize(2);
    display.setCursor(0, 0);
    display.println("!! ALARM !!");
    display.setTextSize(1);
    display.setCursor(0, 22); display.println(alarmMessage);
    display.setCursor(0, 36); display.println("CYCLE AUTO SWITCH");
    display.setCursor(0, 46); display.println("TO CLEAR");
    if ((millis() / 500) % 2 == 0)
      display.drawRect(0, 0, SCREEN_WIDTH, SCREEN_HEIGHT, SSD1306_WHITE);

  } else {
    // Row 1 (large): preset name + mode indicator
    display.setTextSize(2);
    display.setCursor(0, 0);
    display.print(presets[activePreset].name);
    display.setTextSize(1);
    String mStr = (currentMode == MODE_AUTO) ? "AUTO" : "MAN";
    display.setCursor(SCREEN_WIDTH - (mStr.length() * 6), 4);
    display.print(mStr);

    // Row 2 (small): preset label
    display.setTextSize(1);
    display.setCursor(0, 18);
    display.print(presets[activePreset].label);

    display.drawLine(0, 28, SCREEN_WIDTH, 28, SSD1306_WHITE);

    // Row 3: SET RPM
    display.setCursor(0, 32);
    display.print("SET:");
    if (presets[activePreset].fullCoarse) {
      display.print(" FULL COARSE");
    } else {
      char buf[14];
      snprintf(buf, sizeof(buf), "%5d RPM", (int)rampedSetpoint);
      display.print(buf);
      // Ramp-in-progress indicator
      float diff = targetSetpoint - rampedSetpoint;
      if (fabs(diff) > 5.0) {
        display.print(diff > 0 ? " >" : " <");
      }
    }

    // Row 4: ACT RPM
    display.setCursor(0, 44);
    display.print("ACT:");
    if (actualRPM < 10 || magSignalLost()) {
      display.print("  ---- RPM");
    } else {
      char buf[14];
      snprintf(buf, sizeof(buf), "%5d RPM", (int)actualRPM);
      display.print(buf);
    }

    // Row 5: status bar
    display.setCursor(0, 56);
    if (currentMode != MODE_AUTO) {
      display.print("MANUAL");
    } else if (magSignalLost()) {
      display.print("NO MAG SIGNAL");
    } else if (presets[activePreset].fullCoarse) {
      display.print("COARSE >>>>");
    } else {
      float error = rampedSetpoint - actualRPM;
      if (fabs(error) < DEADBAND_RPM) {
        // HOLD: show a stability bar
        display.print("HOLD");
        display.drawLine(28, 60, SCREEN_WIDTH - 2, 60, SSD1306_WHITE);
      } else {
        // Activity bar: width proportional to duty
        float duty = min(fabs(error) / PROP_ZONE_RPM, 1.0f);
        uint8_t barW = (uint8_t)(duty * (SCREEN_WIDTH - 22));
        display.fillRect(22, 56, barW, 8, SSD1306_WHITE);
        // Label inverts over the filled bar
        display.setTextColor(SSD1306_BLACK);
        display.setCursor(2, 56);
        display.print(error > 0 ? "INC" : "DEC");
        display.setTextColor(SSD1306_WHITE);
      }
    }
  }

  display.display();
}


// =============================================================================
// EEPROM
// =============================================================================

void loadSettings() {
  if (EEPROM.read(EE_MAGIC) != EEPROM_MAGIC) {
    // First boot — write defaults
    EEPROM.write(EE_MAGIC, EEPROM_MAGIC);
    EEPROM.put(EE_PRESET1, (uint16_t)PRESET_MAX);
    EEPROM.put(EE_PRESET2, (uint16_t)PRESET_CRUISE_CLIMB);
    EEPROM.put(EE_PRESET3, (uint16_t)PRESET_CRUISE);
    EEPROM.put(EE_PRESET4, (uint16_t)PRESET_ECONOMY);
    Serial.println("EEPROM: defaults written");
  } else {
    uint16_t p1, p2, p3, p4;
    EEPROM.get(EE_PRESET1, p1); presets[0].rpm = p1;
    EEPROM.get(EE_PRESET2, p2); presets[1].rpm = p2;
    EEPROM.get(EE_PRESET3, p3); presets[2].rpm = p3;
    EEPROM.get(EE_PRESET4, p4); presets[3].rpm = p4;
    Serial.println("EEPROM: settings loaded");
  }
}


// =============================================================================
// SERIAL DEBUG CONSOLE
// =============================================================================

void printStatus() {
  Serial.print("Mode=");    Serial.print(currentMode == MODE_AUTO ? "AUTO" : currentMode == MODE_ALARM ? "ALARM" : "MAN");
  Serial.print(" SW=");     Serial.print(presets[activePreset].name);
  Serial.print(" Target="); Serial.print((int)targetSetpoint);
  Serial.print(" Ramped="); Serial.print((int)rampedSetpoint);
  Serial.print(" ACT=");    Serial.print((int)actualRPM);
  Serial.print(" Err=");    Serial.print((int)(rampedSetpoint - actualRPM));
  Serial.print(" Relay=");
  Serial.println(relayState == RELAY_INC ? "INC" : relayState == RELAY_DEC ? "DEC" : "OFF");
}

void handleSerial() {
  if (!Serial.available()) return;
  char c = Serial.read();
  switch (c) {
    case 's': printStatus(); break;
    case 'a': currentMode = MODE_AUTO;   Serial.println("-> AUTO"); break;
    case 'm': currentMode = MODE_MANUAL; relayOff(); Serial.println("-> MANUAL"); break;
    case 'c': clearAlarm(); Serial.println("Alarm cleared"); break;
    case '1': activePreset=0; targetSetpoint=presets[0].rpm; Serial.println("Sim SW->1 MAX"); break;
    case '2': activePreset=1; targetSetpoint=presets[1].rpm; Serial.println("Sim SW->2 CLB"); break;
    case '3': activePreset=2; targetSetpoint=presets[2].rpm; Serial.println("Sim SW->3 CRS"); break;
    case '4': activePreset=3; targetSetpoint=presets[3].rpm; Serial.println("Sim SW->4 ECO"); break;
    case '5': activePreset=4; Serial.println("Sim SW->5 LOW"); break;
    case '?':
      Serial.println("Commands: s=status a=auto m=manual c=clear 1-5=sim_switch ?=help");
      break;
  }
}


// =============================================================================
// SETUP
// =============================================================================
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
void loop() {
  wdt_reset(); // Must be first — resets 250ms watchdog

  uint32_t now = millis();

  // Update RPM from ISR data
  if (newPulse) updateRPM();

  // Read rotary switch with debounce
  int8_t sw = readSwitch();
  if (sw != activePreset) {
    activePreset = sw;
    if (presets[activePreset].fullCoarse) {
      rampedSetpoint = 0; // Emergency — no ramp, engage immediately
    } else {
      targetSetpoint = (float)presets[activePreset].rpm;
      // rampedSetpoint continues from wherever it is now — ramp handles the rest
    }
    Serial.print("Switch -> "); Serial.println(presets[activePreset].name);
  }

  // Update setpoint ramp (runs every loop, very lightweight)
  updateRamp();

  // Serial debug console
  handleSerial();

  // Control loop at 10Hz
  if ((now - lastControlRun) >= CONTROL_INTERVAL_MS) {
    lastControlRun = now;
    runControlLoop();
  }

  // Display at 5Hz
  if ((now - lastDisplayUpdate) >= 200) {
    lastDisplayUpdate = now;
    updateDisplay();
  }

  // Mag signal loss — alarm in AUTO only
  if (currentMode == MODE_AUTO && magSignalLost()) {
    setAlarm("NO MAG SIGNAL");
  }

  // Serial status in AUTO
  static uint32_t lastStatus = 0;
  if (currentMode == MODE_AUTO && (now - lastStatus) >= 2000) {
    lastStatus = now;
    printStatus();
  }
}

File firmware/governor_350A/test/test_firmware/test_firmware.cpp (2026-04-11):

/**
 * Unit tests for governor_350A firmware logic.
 *
 * Strategy: mock all Arduino hardware APIs, then #include the .ino directly
 * so the pure logic functions are compiled into this native translation unit.
 * No hardware required — runs under PlatformIO's native/Unity test runner.
 *
 * Functions under test:
 *   calculateRPM()     — pulse-interval to RPM conversion + rolling average
 *   magSignalLost()    — magneto timeout detection
 *   updateRamp()       — setpoint ramping toward target
 *   runControlLoop()   — proportional relay direction/duty decisions
 */

// Pull in mock headers before the firmware so all Arduino symbols resolve.
#include "Arduino.h"
#include "Wire.h"
#include "EEPROM.h"
#include "Adafruit_GFX.h"
#include "Adafruit_SSD1306.h"
#include "avr/wdt.h"

// Include the firmware itself as a C++ translation unit.
// Forward-declare setAlarm so setRelay() can see it — Arduino IDE auto-generates
// these declarations from .ino files, but standard C++ compilers do not.
void setAlarm(const char* msg);
#include "../../governor_350A.ino"

#include <unity.h>

// =============================================================================
// Test fixture — reset all firmware global state before each test
// =============================================================================

void setUp(void) {
    mock_millis              = 0;
    mock_micros              = 0;
    memset(mock_pin, LOW, sizeof(mock_pin));

    currentMode              = MODE_MANUAL;
    relayState               = RELAY_OFF;
    alarmMessage             = "";

    activePreset             = 2;   // CRUISE
    lastValidPreset          = 2;

    rampedSetpoint           = (float)PRESET_CRUISE;
    targetSetpoint           = (float)PRESET_CRUISE;
    lastRampTime             = 0;

    lastPulseTime_us         = 0;
    pulseInterval_us         = 0;
    newPulse                 = false;

    memset(rpmBuffer, 0, sizeof(rpmBuffer));
    rpmBufIdx                = 0;
    rpmBufFull               = false;

    actualRPM                = 0.0f;
    lastMagPulse_ms          = 0;

    relayOnTime_ms           = 0;
    lastControlRun           = 0;
    lastDisplayUpdate        = 0;
    displayOK                = false;
}

void tearDown(void) {}


// =============================================================================
// calculateRPM() tests
// =============================================================================

void test_rpm_zero_when_no_pulse_interval(void) {
    pulseInterval_us = 0;
    mock_millis      = 1000;
    lastMagPulse_ms  = 999;
    TEST_ASSERT_EQUAL_FLOAT(0.0f, calculateRPM());
}

void test_rpm_zero_when_mag_signal_lost(void) {
    // 8696 µs interval would be ~2300 RPM with 3 PPR, but signal is stale.
    pulseInterval_us = 8696;
    mock_millis      = 5000;
    lastMagPulse_ms  = 0;  // 5 s ago — well past 2 s timeout
    TEST_ASSERT_EQUAL_FLOAT(0.0f, calculateRPM());
}

void test_rpm_correct_for_2300rpm_3ppr(void) {
    // Expected interval: 60,000,000 / (2300 * 3) = 8695.65 µs
    pulseInterval_us = 8696;
    mock_millis      = 1000;
    lastMagPulse_ms  = 999;
    TEST_ASSERT_FLOAT_WITHIN(5.0f, 2300.0f, calculateRPM());
}

void test_rpm_correct_for_2650rpm_3ppr(void) {
    // Expected interval: 60,000,000 / (2650 * 3) = 7547.17 µs
    pulseInterval_us = 7547;
    mock_millis      = 1000;
    lastMagPulse_ms  = 999;
    TEST_ASSERT_FLOAT_WITHIN(5.0f, 2650.0f, calculateRPM());
}

void test_rpm_correct_for_2200rpm_3ppr(void) {
    // Expected interval: 60,000,000 / (2200 * 3) = 9090.9 µs
    pulseInterval_us = 9091;
    mock_millis      = 1000;
    lastMagPulse_ms  = 999;
    TEST_ASSERT_FLOAT_WITHIN(5.0f, 2200.0f, calculateRPM());
}

void test_rpm_rolling_average_smooths_spikes(void) {
    // Fill the averaging buffer with a steady 2300 RPM interval.
    mock_millis     = 1000;
    lastMagPulse_ms = 999;
    for (uint8_t i = 0; i < RPM_AVG_SAMPLES; i++) {
        pulseInterval_us = 8696;
        calculateRPM();
    }
    // Now inject a single spike (4000 RPM equivalent), then read.
    pulseInterval_us = 5000;
    float rpm = calculateRPM();
    // With 8 samples (7 at 8696 + 1 at 5000), average interval ~8321 µs → ~2401 RPM.
    // The key assertion: spike is dampened — result is nowhere near 4000 RPM.
    TEST_ASSERT_TRUE(rpm < 3000.0f);
    TEST_ASSERT_TRUE(rpm > 2000.0f);
}


// =============================================================================
// magSignalLost() tests
// =============================================================================

void test_mag_not_lost_when_fresh(void) {
    mock_millis     = 1000;
    lastMagPulse_ms = 999;  // 1 ms ago
    TEST_ASSERT_FALSE(magSignalLost());
}

void test_mag_not_lost_just_before_timeout(void) {
    mock_millis     = 1999;
    lastMagPulse_ms = 0;    // 1999 ms — just under 2000 ms timeout
    TEST_ASSERT_FALSE(magSignalLost());
}

void test_mag_lost_after_timeout(void) {
    mock_millis     = 2001;
    lastMagPulse_ms = 0;    // 2001 ms > MAG_TIMEOUT_MS (2000)
    TEST_ASSERT_TRUE(magSignalLost());
}


// =============================================================================
// updateRamp() tests
// =============================================================================

void test_ramp_moves_up_toward_higher_target(void) {
    activePreset   = 0;          // MAX — not fullCoarse
    rampedSetpoint = 2200.0f;
    targetSetpoint = 2300.0f;
    lastRampTime   = 0;
    mock_millis    = 500;        // 0.5 s → max step = 50 RPM

    updateRamp();

    TEST_ASSERT_FLOAT_WITHIN(1.0f, 2250.0f, rampedSetpoint);
}

void test_ramp_moves_down_toward_lower_target(void) {
    activePreset   = 0;
    rampedSetpoint = 2300.0f;
    targetSetpoint = 2200.0f;
    lastRampTime   = 0;
    mock_millis    = 500;        // 0.5 s → max step = 50 RPM

    updateRamp();

    TEST_ASSERT_FLOAT_WITHIN(1.0f, 2250.0f, rampedSetpoint);
}

void test_ramp_snaps_when_within_step(void) {
    activePreset   = 0;
    rampedSetpoint = 2295.0f;
    targetSetpoint = 2300.0f;   // only 5 RPM away
    lastRampTime   = 0;
    mock_millis    = 1000;      // 1 s → max step = 100 RPM > 5 RPM diff

    updateRamp();

    TEST_ASSERT_EQUAL_FLOAT(2300.0f, rampedSetpoint);
}

void test_ramp_does_not_overshoot(void) {
    activePreset   = 0;
    rampedSetpoint = 2299.0f;
    targetSetpoint = 2300.0f;
    lastRampTime   = 0;
    mock_millis    = 5000;      // huge elapsed time — must snap, not overshoot

    updateRamp();

    TEST_ASSERT_EQUAL_FLOAT(2300.0f, rampedSetpoint);
}

void test_ramp_bypassed_for_fullcoarse_preset(void) {
    activePreset   = 4;         // LOW/EMERGENCY — fullCoarse = true
    rampedSetpoint = 2200.0f;
    targetSetpoint = 0.0f;
    lastRampTime   = 0;
    mock_millis    = 1000;

    updateRamp();

    // rampedSetpoint must not change when fullCoarse is active.
    TEST_ASSERT_EQUAL_FLOAT(2200.0f, rampedSetpoint);
}
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

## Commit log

2026-03-09 File cleanup
    [350A_governor.kicad_pcb]
2026-03-09 Change in switch architecture
    [350A_governor.kicad_pcb]
2026-03-12 Fiverr design.
    [350A_governor.kicad_pcb, positions.csv]
2026-03-13 Project cleanup
    [350A_governor.kicad_pcb, positions.csv]
2026-04-06 Fix duplicate INT0 vector causing linker error
    Removed bare ISR(INT0_vect) block that conflicted with the attachInterrupt() lambda in setup(). Both claimed __vector_1 (INT0), causing a multiple definition linker error.
    [governor_350A.ino]
2026-04-06 Add PlatformIO build configuration
    Adds platformio.ini for the governor_350A firmware targeting Arduino Nano
    (ATmega328P). Pins Adafruit SSD1306 and GFX library versions; compiles
    clean with no warnings (Flash 78%, RAM 67%).
2026-04-06 Add Unity unit tests for firmware logic (24 tests, all passing)
    Tests mock all Arduino/AVR hardware APIs and include the .ino directly,
    allowing pure logic functions to be exercised on the native desktop without
    hardware. Covers:
    - calculateRPM: interval-to-RPM math, rolling average, timeout gating
    - magSignalLost: threshold boundary conditions
    - updateRamp: direction, step size, snap-to-target, fullCoarse bypass
    - runControlLoop: INC/DEC relay selection, deadband, alarm triggers,
    proportional duty, full-coarse mode
    Build: pio test -e native (requires GCC) or MSVC manually via .pio/build_test.bat.
    [test_firmware.cpp]
2026-04-06 Add firmware README with flashing guide and test documentation
    Documents three flashing methods (Arduino IDE, PlatformIO, Arduino CLI)
    with step-by-step instructions including bootloader variant gotchas and
    expected serial output. Covers the serial debug console commands, all
    tuning parameters, and unit test coverage — including an explicit section
    on what is not testable without hardware and why. Updates root README repo
    structure map and Quick Start step to link to the new firmware README.
2026-04-11 Updated BOM with shopping lists
2026-04-12 Fix relay driver: replace ULN2003A (low-side) with NPN+PNP high-side circuit
    The Bonanza relay coil wiring is high-side driven: governor supplies +12V
    to the coil, the other end grounds through the pitch-limit switch. The
    ULN2003A is an NPN low-side switch and is incompatible with this topology.
    Hardware fix (BOM/WIRING):
    - Remove ULN2003A; add 2x 2N2907A (PNP) + 2x 2N2222A (NPN) per relay channel
    - Add R5/R6 (1kΩ NPN base resistors) and R7/R8 (10kΩ PNP base pull-ups)
    - Add D3/D4 (1N4001 flyback diodes, J1-C/D to J1-A) for inductive spike clamping
    - Remove DIP-16 socket (no longer needed)
    - WIRING.md: correct "identical behavior" claim; document PNP high-side requirement;
    update Nano pi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
    [governor_350A.ino]
2026-04-12 Add PCB Rev 2 brief for Fiverr engineer
    Documents the relay driver redesign (ULN2003A → NPN+PNP high-side)
    with component list, circuit connections, and JLCPCB deliverables.
2026-04-14 PCB Revisions after changes suggested
2026-04-20 Latest PCB version
    [2N2222A.step, 2N2907A_.step, 350A_governor.kicad_pcb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]
2026-04-27 Rev 3 Hardware Delivery and name changes
    [2N2222A.step, 2N2907A_.step, 350A_governor.kicad_pcb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]
2026-04-27 Rev 3_1 PCB and project lcleanup
    [2N2222A.step, 2N2907A_.step, 350A_governor.kicad_pcb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]
2026-04-27 More cleanup
    [350A_governor-B_Cu.gbl, 350A_governor-B_Mask.gbs, 350A_governor-B_Silkscreen.gbo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]
2026-04-27 Updated schematic
